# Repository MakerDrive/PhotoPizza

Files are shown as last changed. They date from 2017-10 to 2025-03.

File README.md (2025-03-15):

Watch the promo video (https://youtu.be/ocshAWL1mxE?si=FHEazX_rP1Yjf2Of)

# 📷 PhotoPizza DIY

**PhotoPizza** is an open-source project for creating a turntable that allows you to take pictures of objects from all directions (3D-photo-360 spin-photo). The control unit platform is based on Espruino.

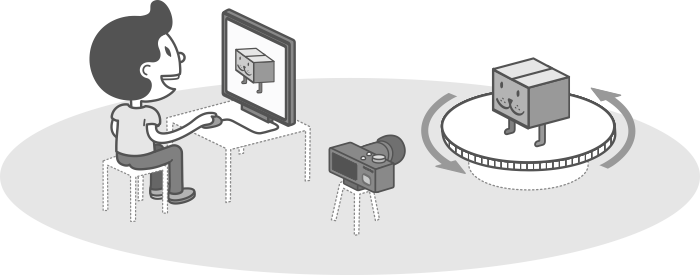
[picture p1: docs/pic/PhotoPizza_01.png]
PhotoPizza Turntable


## 📚 Documentation

Our documentation is organized into several sections for easier navigation:

1. [📢 About PhotoPizza](docs/01-about.md) - Project overview and message from the author
2. [🛠️ Hardware Requirements](docs/02-hardware.md) - List of components needed for the control unit
3. [🔄 Turntable Models](docs/03-turntable-models.md) - Different turntable sizes and their components
4. [📱 Control Methods](docs/04-control-methods.md) - IR Remote, Android App, and Wi-Fi control
5. [📸 Operation Guide](docs/05-operation-guide.md) - How to use PhotoPizza for shooting and calibration
6. [🌟 Join the Community](docs/06-community.md) - How to contribute and contact information
7. [🏺 3D Scanning Examples](docs/07-3d-scanning-examples.md) - Real-world examples of 3D scanning projects
8. [📰 Latest News](docs/08-news.md) - Recent updates and announcements

## ✨ Features

- 🔄 360° product photography
- 📱 Multiple control options (IR remote, Android app, Wi-Fi)
- 🛠️ DIY-friendly design
- 📊 Customizable shooting parameters
- 🎥 Support for both photo and video shooting
- 📐 Various turntable sizes (D250, D340, D480, D700, D850)
- 🔍 3D scanning with laser scanners
- 📷 3D scanning using photogrammetry methods

## 🚀 Quick Start

1. Choose your turntable size based on your needs
2. Gather all the required components
3. Follow the assembly instructions
4. Install the firmware
5. Connect to your camera
6. Start shooting amazing 360° photos!

## 📥 Downloads

- [📱 Android App](https://github.com/PhotoPizza/remote/blob/master/PhotoPizza.apk)
- [💾 Firmware](Firmware_for_D340_D480_D700/)
- [📐 Laser Cutting Drawings](Drawings_for_laser_cutting/)

## 📚 Related Articles
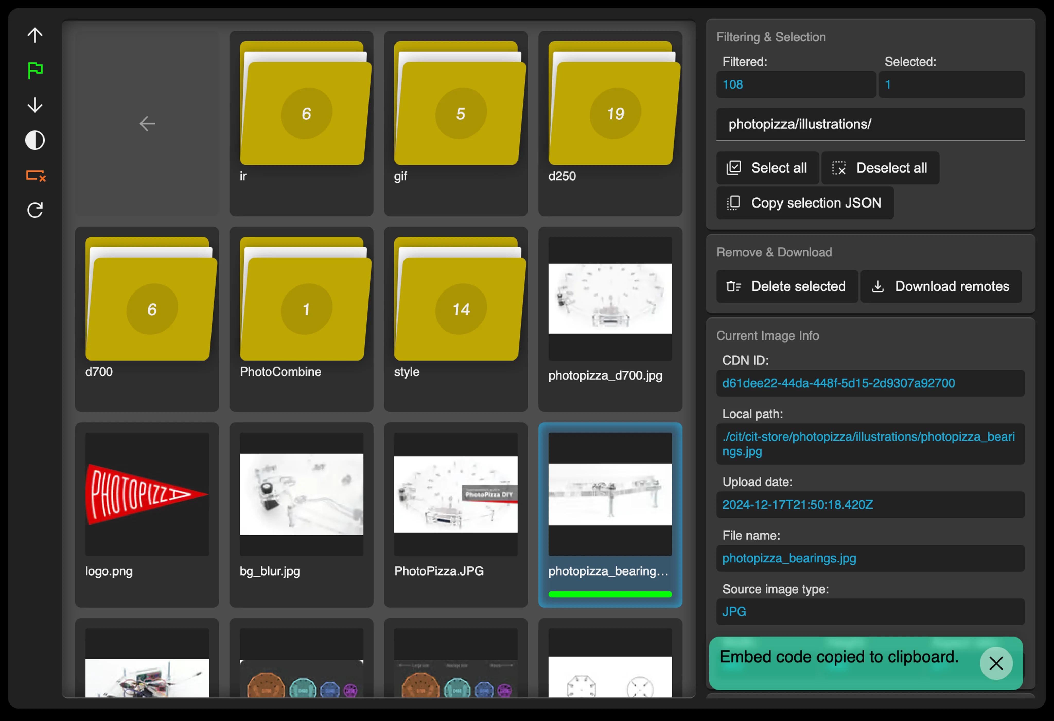
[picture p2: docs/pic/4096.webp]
PhotoPizza in action


- [📝 PhotoPizza: From the idea to the Open Source DIY Project](https://rnd-pro.com/pulse/PhotoPizza/)
- [📝 Interactive Media Spots](https://rnd-pro.com/pulse/interactive-media-spots/)
- [📝 ComplexScan AUTOBOX v1](https://rnd-pro.com/pulse/ComplexScan_AUTOBOX_v1/)
- [📝 ComplexScan](https://rnd-pro.com/pulse/ComplexScan/)
- [📝 Web Images: Problems and Solutions](https://rnd-pro.com/pulse/web-images-problem/)

## 📱 Social Media

Follow us on social media for updates, tips, and community showcases:

- [📸 Instagram](https://www.instagram.com/diy.photopizza/)
- [🎬 YouTube](https://www.youtube.com/@PhotoPizza)

## 📞 Contact

For inquiries, please contact: photopizza@rnd-pro.com

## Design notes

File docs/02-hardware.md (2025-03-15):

# 🛠️ Hardware Requirements

## External Control Unit

### 🔌 Electronics

- ESP32 Controller - 1
- Relay - 1
- Stepper motor driver board - 1
- Stepper motor driver - 1
- Heat sink - 1
- Power contact expansion board - 1
- IR receiver - 1
- Display - 1
- 3.5 Jack connector - 1
- Fan - 1
- Batteries for IR remote - 2

### 📦 Body Parts

- Base - 1
- Cover - 1
- Front panel - 1
- Screen mounting panel - 1
- Left panel with 3.5 Jack cutout - 1
- Right panel: fan - 1
- Rear panel - 1
- 3.5 Jack mounting part - 1
- IR receiver mounting part - 1
- IR remote - 1

### 🔩 Fasteners

- Screw 3*16 - 22
- Screw 3*25 - 2
- Nut M3 - 33
- Countersunk screw 6*35 - 4
- Nut M6 - 4
- Furniture nut M6 - 4

### 🧵 Wires

- Power wire 5V: male-female "+" 12 cm - 3
- Power wire 5V: male-female "-" 12 cm - 3
- Power wire 5V: female-female "+" 12 cm - 3
- Power wire 5V: female-female "-" 12 cm - 3
- Power wire 12V: male-male "+" long - 1
- Power wire 12V: male-male "-" long - 1
- Control wire: male-male 12 cm - 3
- Control wire: male-female 12 cm - 5
- Extension wire 3.5 Jack - 1
- Sync wire - 1

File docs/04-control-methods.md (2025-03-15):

# 📱 Control Methods

## 🎮 IR Remote Control

### Description of IR Remote Buttons

1. **Parameter control buttons:**
   - `1-9, 0`: Enter numerical values for various parameters.
   - `UP`: Move up through the menu.
   - `DOWN`: Move down through the menu.
   - `LEFT`: Move left through the menu.
   - `RIGHT`: Move right through the menu.
   - `OK`: Confirm selection or change a parameter, start and stop the shooting process.
   - `SETUP`: Enter and exit the parameter setup menu.

2. **Special buttons:**
   - `SAVE`: Save the current settings.
   - `SHOT`: Test shot.
   - `CALIBR`: System calibration.
   - `WIFI`: Enable Wi-Fi.

### How to Use the IR Remote Control

The remote allows you to fully control the turntable, set shooting parameters, and start/stop the shooting process.

## 📱 Android Application

### PhotoPizza Remote App

Now an official Android application is available that allows you to control the PhotoPizza turntable via Wi-Fi connection. The application provides a convenient interface for setting shooting parameters, starting and stopping the process, and saving configurations.

### ✨ Main Features:

- Connect to the PhotoPizza device via Wi-Fi
- Configure all shooting parameters (number of frames, delay, pause, speed, rotation angle)
- Start and stop the shooting process
- Calibrate the turntable
- Save and load user settings
- Test shot
- Infinite rotation mode for video shooting

### 📥 Where to Download:

- Project repository: [https://github.com/PhotoPizza/remote](https://github.com/PhotoPizza/remote)
- Download APK file: [https://github.com/PhotoPizza/remote/blob/master/PhotoPizza.apk](https://github.com/PhotoPizza/remote/blob/master/PhotoPizza.apk)

### 📋 Requirements:

- Android 5.0 or higher
- PhotoPizza device with firmware v7 (ESPRUINO) or newer
- Wi-Fi connection

### 🔌 First Connection Guide

The initial setup of the Android application involves the following steps:

1. **Create a Hotspot on Your Phone:**
   - Create a mobile hotspot with SSID `PhotoPizza` and password `9992030360`.
   - This will allow the control unit to connect to your phone directly.

2. **Power On the Control Unit:**
   - Turn on the PhotoPizza control unit.
   - During startup, the control unit will automatically connect to the hotspot you created.

3. **Connect Through the App:**
   - Open the PhotoPizza Remote app on your Android device.
   - The app will automatically detect and connect to the control unit.

4. **Optional: Configure for Home Network:**
   - You can continue using the hotspot method, or configure the system to use your home Wi-Fi network.
   - To use your home network, go to the app settings.
   - Enter your home Wi-Fi network parameters (SSID and password).
   - Save the settings.
   - Restart the control unit, and it will connect to your home network instead.
   - Your phone, when connected to the same home network, will be able to control the turntable without creating a hotspot.

## 🌐 Wi-Fi Control

### Connecting to Wi-Fi

The system can operate in two modes:

1. **Access Point (AP):**
   - The device creates an access point with SSID `PhotoPizza` and password `9992030360`.
   - To select this mode, set the `wirelessType` parameter to `ap`.

2. **Connecting to an Existing Network (Client):**
   - To connect to an existing network, set the `wirelessType` parameter to `conn`.
   - Set the network SSID in the `wifiSsid` parameter and the password in the `wifiPassword` parameter.

### Web Server

Wi-Fi control is an additional way to control the system. Through the web interface, you can manage the system state, change settings, and get current data.

1. The system launches a WebSocket server on the port specified in the configuration (`wsPort`).
2. Through the web interface, you can manage the system state, change settings, and get current data.

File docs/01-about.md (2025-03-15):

# 📢 About PhotoPizza

## A Message from the Author

**I had to leave my country. Currently, I don't have access to the equipment needed for developing and testing the project, but I plan to restore the project description and publish all the materials developed before my departure soon.**

**I am looking for like-minded individuals worldwide who want to earn money from the open-source project, sell ready-made equipment, and participate in its development. I will post your contact information on the website, provide additional information, and packaging blueprints. Clients who don't have time to assemble the equipment themselves will reach out to you. I will not take any percentage of your profit. You will be the official representatives of this project in your country.**

**For inquiries, please contact photopizza@rnd-pro.com.**

## 🔄 360° Product Photography Turntable

**PhotoPizza** is an open-source project for creating a turntable that allows you to take pictures of objects from all directions (3D-photo-360 spin-photo). The control unit platform is based on Espruino. You can self-assemble the device from available components using detailed instructions, and you do not need deep knowledge in electronics. The turntable is also suitable for 3D scanning using photogrammetry methods.

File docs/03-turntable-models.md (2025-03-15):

# 🔄 Turntable Models

## Turntable D340

### Acrylic Parts

- Base - 1
- Disk 340 cm - 1
- Motor mount - 1
- Motor spacer - 1
- Background disk, white 34 cm

### Fasteners

- Bearings 608ZZ for rollers - 8
- Bolt 8*40 for rollers and central axis - 9
- Nuts M8 for rollers, central axis, and legs - 26
- Clamps for rollers - 8
- Screw M8x60 DIN912 (legs) - 8
- Wing nuts M8 for leg mounting - 8
- Screw M6x35 for clamping system - 3
- Nut M6 for clamping system - 6
- Screw M3x16 for motor mounting - 4
- Spring for clamping system - 2
- Drive roller - 1
- Rubber for drive roller - 4

### Electrical Components

- Nema 17 stepper motor - 1
- Wire for motor connection - 1

## Turntable D480

### Acrylic Parts

- Base - 1
- Disk 480 cm - 1
- Motor mount - 1
- Motor spacer - 1
- Background disk, white 48 cm

### Fasteners

- Bearings 608ZZ for rollers - 12
- Bolt 8*40 for rollers and central axis - 13
- Nuts M8 for rollers, central axis, and legs - 38
- Clamps for rollers - 12
- Screw M8x60 DIN912 (legs) - 12
- Wing nuts M8 for leg mounting - 12
- Screw M6x35 for clamping system - 3
- Nut M6 for clamping system - 6
- Screw M3x16 for motor mounting - 4
- Spring for clamping system - 2
- Drive roller - 1
- Rubber for drive roller - 4

### Electrical Components

- Motor - 1
- Wire for motor connection - 1

## Turntable D700

### Acrylic Parts

- Base - 1
- Disk 70 cm - 1
- Motor mount - 1
- Motor spacer - 1
- Background disk, white 70 cm

### Fasteners

- Bearings 608ZZ for rollers - 24
- Bolt 8*40 for rollers and central axis - 25
- Nuts M8 for rollers, central axis, and legs - 62
- Clamps for rollers - 24
- Screw M8x60 DIN912 (legs) - 12
- Wing nuts M8 for leg mounting - 12
- Screw M6x35 for clamping system - 3
- Nut M6 for clamping system - 6
- Screw M3x16 for motor mounting - 4
- Spring for clamping system - 2
- Drive roller - 1
- Rubber for drive roller - 4

### Electrical Components

- Motor - 1
- Wire for motor connection - 1

## Turntable D850

### Acrylic Parts

- Base - 1
- Disk 85 cm - 1
- Motor mount - 1
- Motor spacer - 1
- Background disk, white 85 cm

### Fasteners

- Bearings 608ZZ for rollers - 24
- Bolt 8*40 for rollers and central axis - 25
- Nuts M8 for rollers, central axis, and legs - 62
- Clamps for rollers - 24
- Screw M8x60 DIN912 (legs) - 12
- Wing nuts M8 for leg mounting - 12
- Screw M6x35 for clamping system - 6
- Nut M6 for clamping system - 12
- Screw M3x16 for motor mounting - 8
- Spring for clamping system - 4
- Drive roller - 2
- Rubber for drive roller - 8

### Electrical Components

- Motor - 2
- Wire for motor connection - 2

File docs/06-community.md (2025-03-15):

# 🌟 Join the Community

**PhotoPizza** is a great opportunity to create 3D photos and spin photos yourself. Join our community and help make the project even better!

## 📞 Contact Information

- 📧 Email: photopizza@rnd-pro.com
- 🌐 GitHub: [https://github.com/MakerDrive/PhotoPizza](https://github.com/MakerDrive/PhotoPizza)
- 📱 Android App: [https://github.com/PhotoPizza/remote](https://github.com/PhotoPizza/remote)

## 🤝 How to Contribute

We welcome contributions from the community! Here are some ways you can help:

1. **Development**: Improve the firmware, add new features, fix bugs
2. **Documentation**: Help improve or translate the documentation
3. **Testing**: Test the device and report issues
4. **Spread the word**: Share your experience with the project on social media
5. **Become a representative**: Sell ready-made equipment in your country

## 📸 Share Your Projects

We'd love to see what you create with PhotoPizza! Share your projects, photos, and videos with the community.

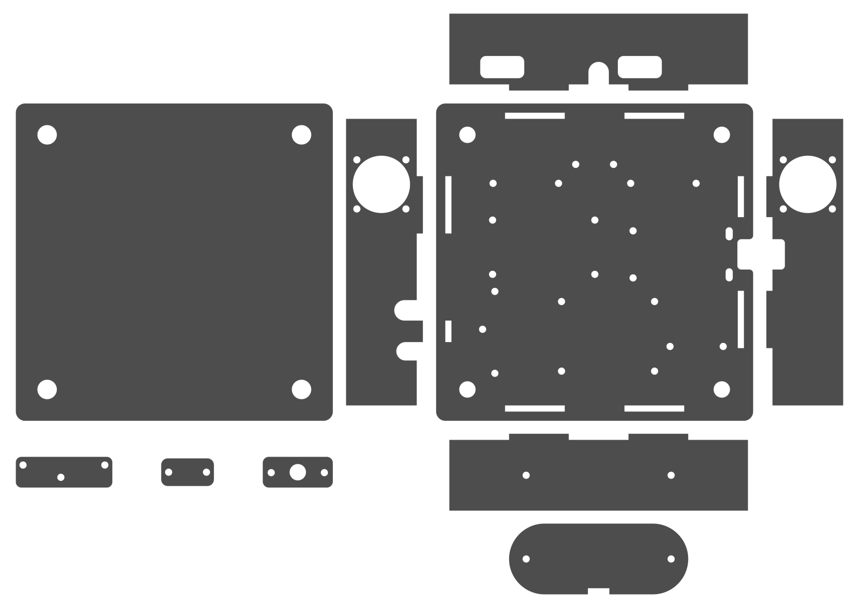
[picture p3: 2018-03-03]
Drawings_for_laser_cutting/Drawings_PhotoPizza_v3-5/PhotoPizza_Control_Unit_v5_Thickness_3mm/ESP32/Control Unit v5.jpg

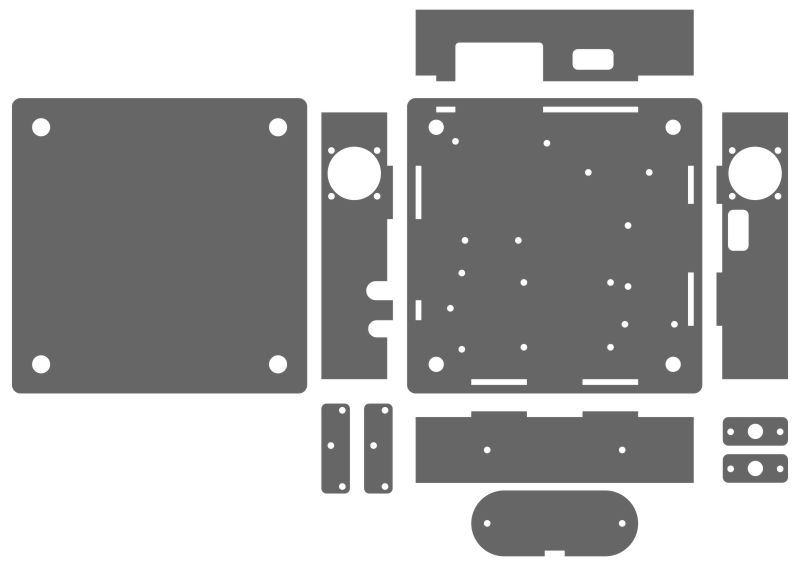
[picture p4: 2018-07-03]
Drawings_for_laser_cutting/Drawings_PhotoPizza_v3-5/PhotoPizza_Control_Unit_v5_Thickness_3mm/ESP32UNO/Control Unit v5.jpg

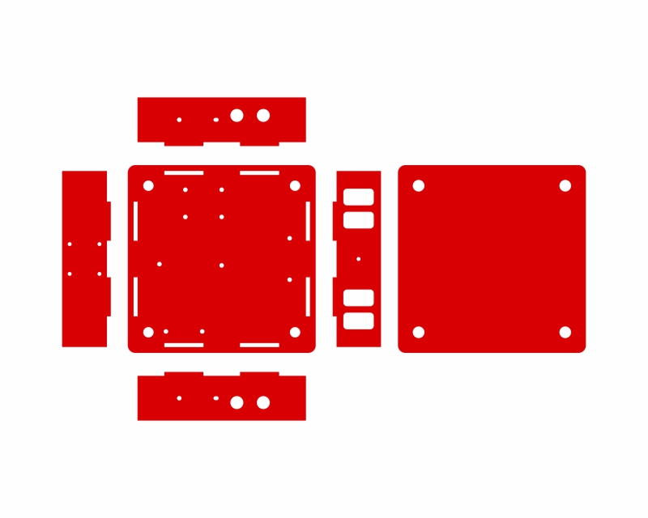
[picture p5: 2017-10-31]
Drawings_for_laser_cutting/Drawings_PhotoPizza_v3-5/PhotoPizza_Control_Unit_v3-4_Thickness_3mm/PhotoPizza Control block v3.jpg

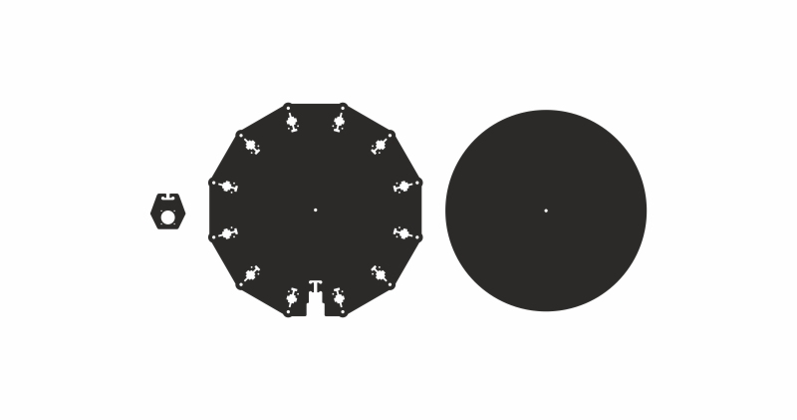
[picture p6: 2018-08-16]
Drawings_for_laser_cutting/Drawings_PhotoPizza_v3-5/PhotoPizza_D480_v3-5_Thickness_10mm/PhotoPizza D480 v3.jpg

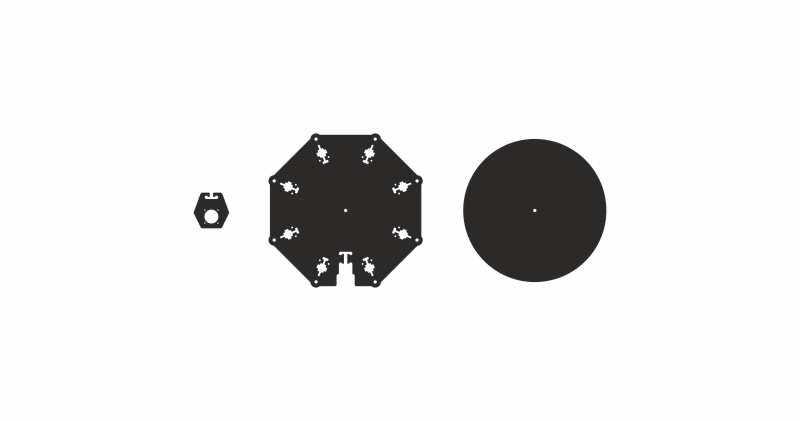
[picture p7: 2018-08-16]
Drawings_for_laser_cutting/Drawings_PhotoPizza_v3-5/PhotoPizza_D340_v3-5_Thickness_10mm/PhotoPizza D340 v3.jpg

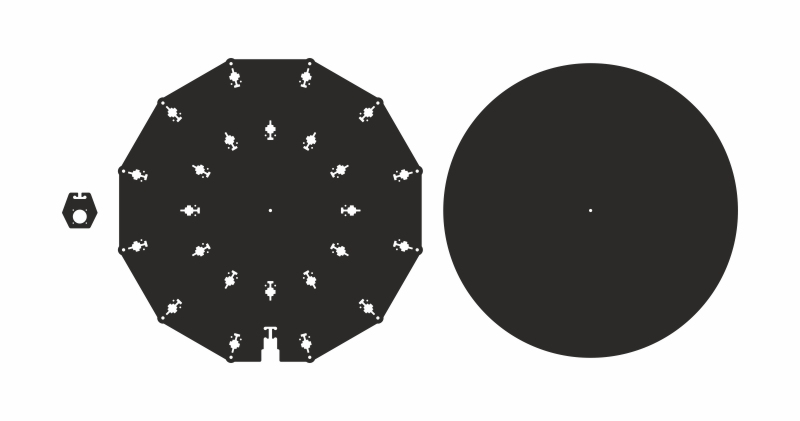
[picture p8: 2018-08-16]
Drawings_for_laser_cutting/Drawings_PhotoPizza_v3-5/PhotoPizza_D700_v3-5_Thickness_10mm/PhotoPizza D700 v3.jpg

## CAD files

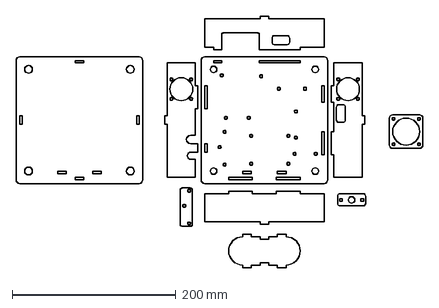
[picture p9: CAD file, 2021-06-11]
Drawings_for_laser_cutting/Drawings_PhotoPizza_v7/PhotoPizza_Control_Unit_v7_Thickness_3mm/PhotoPizza_Control_Unit_v7_Thickness_3mm.dxf
497.7 x 307.1 mm

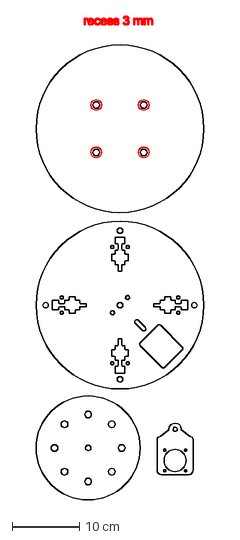
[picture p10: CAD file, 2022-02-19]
Drawings_for_laser_cutting/Drawings_PhotoPizza_v7/PhotoPizza_D250_v7_Thickness_10mm/D250.dxf
25.0 x 72.1 cm

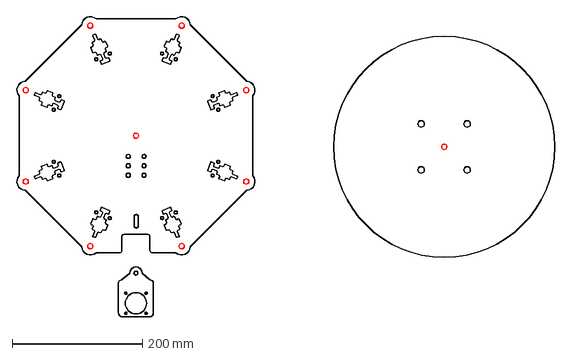
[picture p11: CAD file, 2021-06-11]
Drawings_for_laser_cutting/Drawings_PhotoPizza_v7/PhotoPizza_D340_v7_Thickness_10mm/PhotoPizza_D340_v7_Thickness_10mm.dxf
828.2 x 462.6 mm

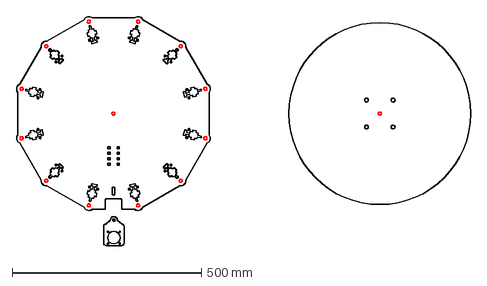
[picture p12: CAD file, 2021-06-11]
Drawings_for_laser_cutting/Drawings_PhotoPizza_v7/PhotoPizza_D480_v7_Thickness_10mm/PhotoPizza_D480_v7_Thickness_10mm.dxf
1199.8 x 605.3 mm

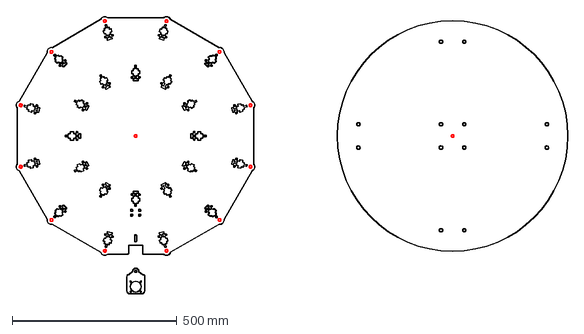
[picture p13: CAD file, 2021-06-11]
Drawings_for_laser_cutting/Drawings_PhotoPizza_v7/PhotoPizza_D700_v7_Thickness_10mm/PhotoPizza_D700_v7_Thickness_10mm.dxf
1675.6 x 841.3 mm

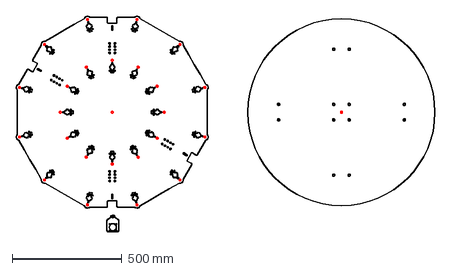
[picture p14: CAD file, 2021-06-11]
Drawings_for_laser_cutting/Drawings_PhotoPizza_v7/PhotoPizza_D850_v7_Thickness_10mm/PhotoPizza_D850_v7_Thickness_10mm.dxf
1904.6 x 981.7 mm

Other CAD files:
Drawings_for_laser_cutting/Drawings_PhotoPizza_v3-5/PhotoPizza_Control_Unit_v5_Thickness_3mm/ESP32/Control Unit v5.dwg
Drawings_for_laser_cutting/Drawings_PhotoPizza_v3-5/PhotoPizza_Control_Unit_v5_Thickness_3mm/ESP32UNO/Control Unit v5.dwg
Drawings_for_laser_cutting/Drawings_PhotoPizza_v3-5/PhotoPizza_D340_v3-5_Thickness_10mm/PhotoPizza D340 v3.dwg
Drawings_for_laser_cutting/Drawings_PhotoPizza_v3-5/PhotoPizza_D480_v3-5_Thickness_10mm/PhotoPizza D480 v3.dwg
Drawings_for_laser_cutting/Drawings_PhotoPizza_v3-5/PhotoPizza_D700_v3-5_Thickness_10mm/PhotoPizza D700 v3.dwg
Drawings_for_laser_cutting/Drawings_PhotoPizza_v7/PhotoPizza_Control_Unit_v7_Thickness_3mm/PhotoPizza_Control_Unit_v7_Thickness_3mm.dwg
Drawings_for_laser_cutting/Drawings_PhotoPizza_v7/PhotoPizza_D250_v7_Thickness_10mm/D250.dwg
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

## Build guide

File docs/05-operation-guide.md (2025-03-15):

# 📸 Operation Guide

## 📷 Shooting Process

1. **Object Placement:**
   - Place the item you want to photograph on the turntable.

2. **Setting Parameters:**
   - Use the IR remote or Android app to set the necessary shooting parameters:
     - Number of frames (`frame`).
     - Delay (`delay`) - delay time in milliseconds (e.g., `1000` milliseconds = 1 second).
     - Pause (`pause`) - pause time in milliseconds (e.g., `500` milliseconds = 0.5 seconds).
     - Speed (`speed`) - rotation speed in steps per second.
     - Rotation angle (`degreesX`) - rotation angle in degrees.

3. **Start Shooting:**
   - Press the `OK` button on the IR remote or the corresponding button in the app to confirm the settings.
   - To start the shooting process, press the `OK` button again. The turntable will start rotating and taking pictures automatically according to the set parameters.

4. **Stop Shooting:**
   - To stop the shooting process, press the `OK` button again.

5. **Infinite Shooting:**
   - To enable the infinite shooting mode, use the `"infinity"` command.

6. **Video Shooting:**
   - For video shooting, set the parameters for continuous rotation and turn on the camera in video mode. The turntable will rotate smoothly, providing even shooting from all sides.

7. **Saving Settings:**
   - After shooting, if you want to save the current settings for future shoots, press the `SAVE` button on the IR remote or use the save function in the app.

## 🔄 Calibration Process

### Why Calibration is Needed

Turntable calibration is necessary for accurately determining the rotation angle and ensuring correct object positioning. This allows the table to rotate precisely 360 degrees, returning to the starting point, which is important for creating high-quality 3D models, panoramic photos, and video shooting.

### Calibration Steps

1. **Preparation:**
   - Place the item opposite the drive roller on the turntable.

2. **Start Calibration:**
   - Press the `CALIBR` button on the IR remote or use the calibration function in the app to start the calibration process.

3. **Calibration Process:**
   - The turntable will start rotating. Stop it when the disk has rotated 360 degrees and is opposite the drive roller.
   - To stop the rotation, press the `OK` button.

4. **Saving Calibration:**
   - After completing the calibration process, press the `SAVE` button on the IR remote or use the save function in the app to save the settings.

## ⚙️ System Management

### Saving Configuration

To save the current settings, use the "Save Config" command in the management interface or press the `SAVE` button on the IR remote.

### Connecting to Wi-Fi

1. When connecting to Wi-Fi, the status is displayed on the screen.
2. If the connection is lost, the system will automatically attempt to reconnect.

## 📊 Working with Screens

### Status Display

The screen displays current settings and system status, such as the number of remaining frames, speed, and IP address.

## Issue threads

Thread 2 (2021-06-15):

photopizza_esp32_v7_2_old_pin.min.js

tornadocoin, 2021-06-15:
the code is unreadable. The device does not work after uploading

ajayjob2011, 2021-08-24:
> the code is unreadable. The device does not work after uploading

The code is working, But my stepper gets hot.

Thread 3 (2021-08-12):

Code incompatible with the last Espruino Firmware

BullzLabz, 2021-08-12:
Hello, thank you for this amazing project!

Could you please update the code for it work with the **latest Espruino Firmware 2v09** ?

Or give the guidelines and directives so that I can help you and contribute to your project by updating the code.

I tried to upload your code on all versions of Espruino Firmware, but only the **1v95** version works.

ajayjob2011, 2021-08-24:
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

Hi friend, Direct upload this v7 Espruino ESP32 it's working fine.

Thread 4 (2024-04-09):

project still alive?

MattFog, 2024-04-09:
I'd like to build a Photopizza, but I can't seem to find overall instructions, BOM, guide, etc.  The website appears to be down as well - does anyone know the status?

TheSchirki, 2024-06-10:
Same question here. @3d-photo-360 is it possible that you have a look on your website?

trueslator, 2024-07-01:
Couple of years ago, I bought a turntable for the company where I'm working for. This was way before the world got crazy in 2022. This turntable is still alive and working fine. In the past, I build a second controller and constructed a housing out of the drawings for 3D printing, I'm visiting our warehouse tomorrow to do some trainings/workshop for product photos. I will take detailed photos of the original turntable because I will build another one for my selfe. I will get some idea how to assamble it. The laser cutter drawings will help me to build one out of playwood. With a 400mm by 400mm - 20watt laser cutter/engraver I assume that I can build a 380mm version. I have also some more stuff to share, maybe it could be helpfull for someone. Let me know I should share my informations and stuff with you?

TheSchirki, 2024-07-02:
@trueslator  for me it would be interesting to get a manual to assemble the physical parts of the table, but that's not my main issue. It would be great to have a list of electrical parts needed, a wiring plan and how to set up the system.

trueslator, 2024-07-02:
@TheSchirki this would be possible. I build one controller by myself and use it for 360° panorama photos like this: http://www.meine-bilderbox.de/pano/thiele/thiele01.html and for a slider - the controller is very flexible. Give me a couple of days to find the original order which I did via Ali Express. Also the wiring wasn't that complicated.

trueslator, 2024-07-13:
I have reconstructed the controller unit with fritzing and have also the BOM available. I already found that somebody forked this project. I can share my data that this can be uploaded to the forked project, Any idea how to contact the owner of the forked project?

TheSchirki, 2024-07-18:
Where did you find a forked project? could you link it? And I'd appreciate it if you would upload your data there.

trueslator, 2024-07-18:
The creator of this issue forked it back in April. [PhotoPizza-2024](https://github.com/dangerweenie/PhotoPizza-2024). I can't add something to this forked project because the upload is blocked.

TheSchirki, 2024-07-24:
@trueslator I saw that you forked @dangerweenie s project. Would you upload your schematics and a brief instruction?

TheSchirki, 2024-07-24:
Because I'm quite new to coding and I don't really get what the "Firmware V7_6" or why there's nothing about the motor controlling. Same with all the Header files in the Arduino folder. The way I used and coded an Arduino were quite different. So I'm basically standing in front of all the code snippets and have no idea where to start or what to do with them. Any help is deeply appreciated.

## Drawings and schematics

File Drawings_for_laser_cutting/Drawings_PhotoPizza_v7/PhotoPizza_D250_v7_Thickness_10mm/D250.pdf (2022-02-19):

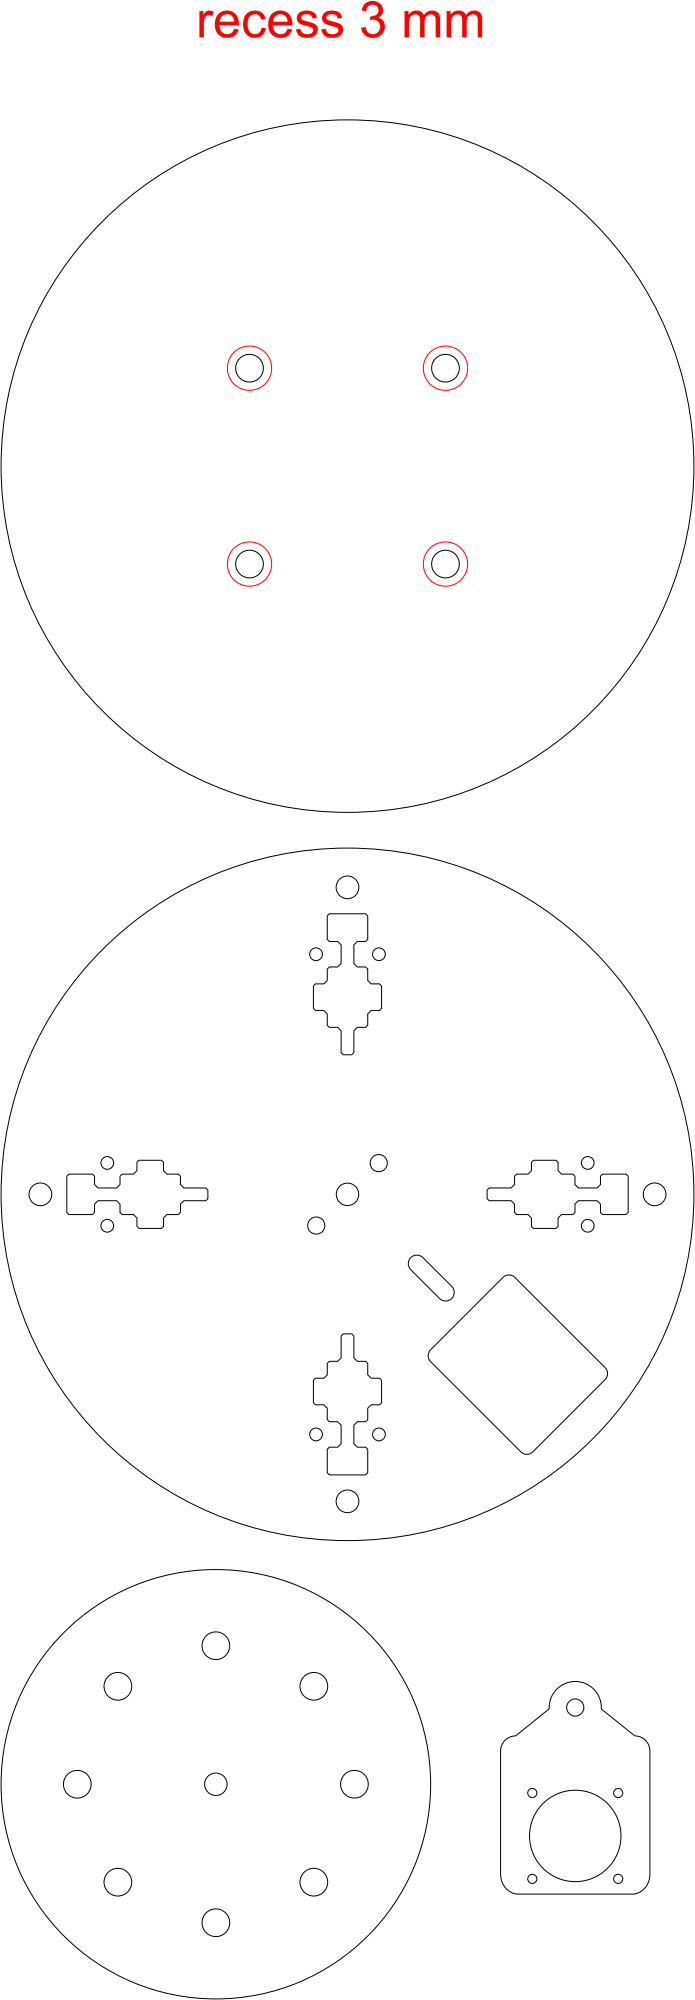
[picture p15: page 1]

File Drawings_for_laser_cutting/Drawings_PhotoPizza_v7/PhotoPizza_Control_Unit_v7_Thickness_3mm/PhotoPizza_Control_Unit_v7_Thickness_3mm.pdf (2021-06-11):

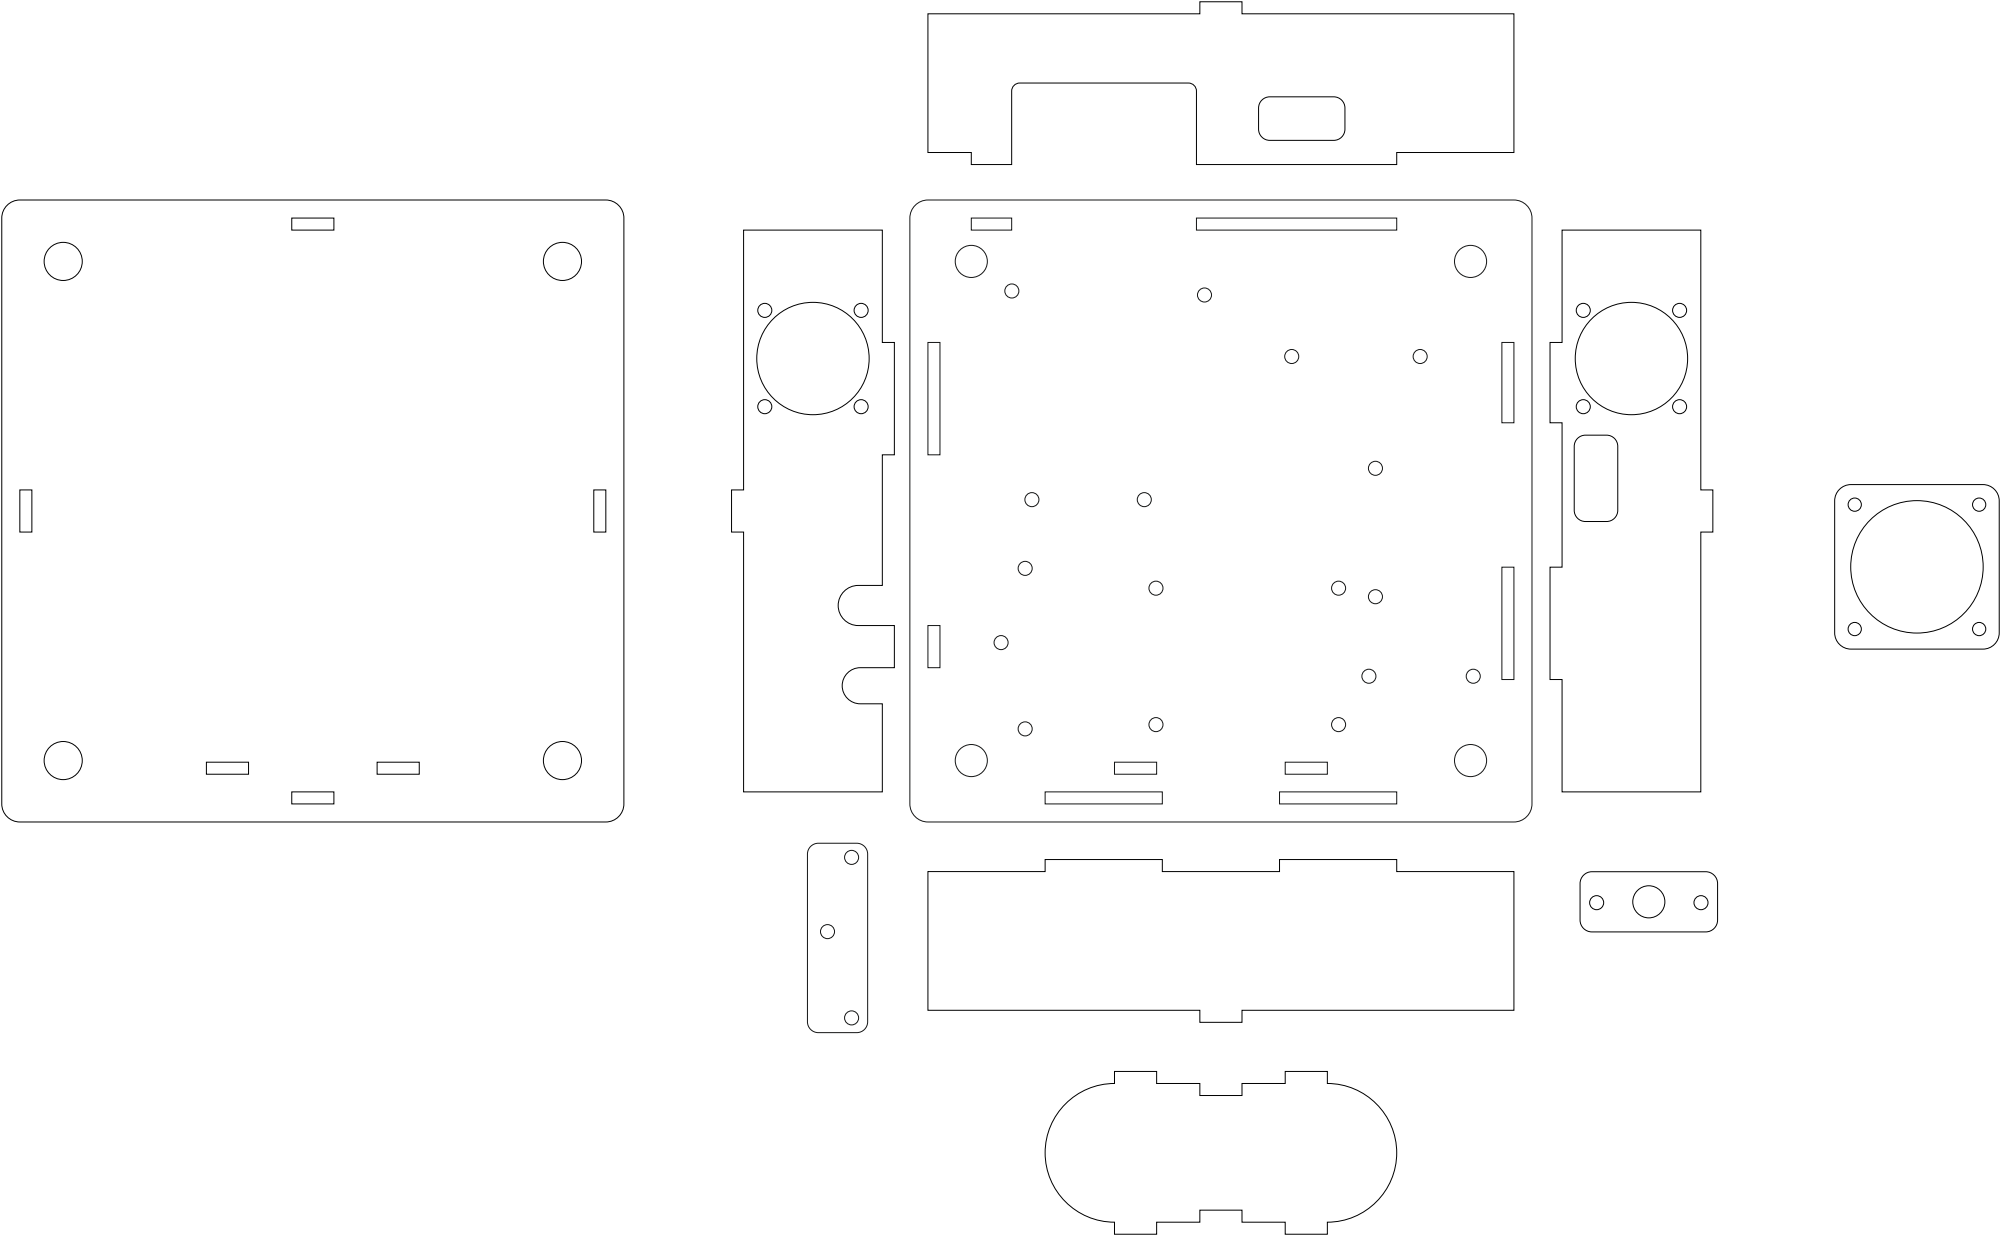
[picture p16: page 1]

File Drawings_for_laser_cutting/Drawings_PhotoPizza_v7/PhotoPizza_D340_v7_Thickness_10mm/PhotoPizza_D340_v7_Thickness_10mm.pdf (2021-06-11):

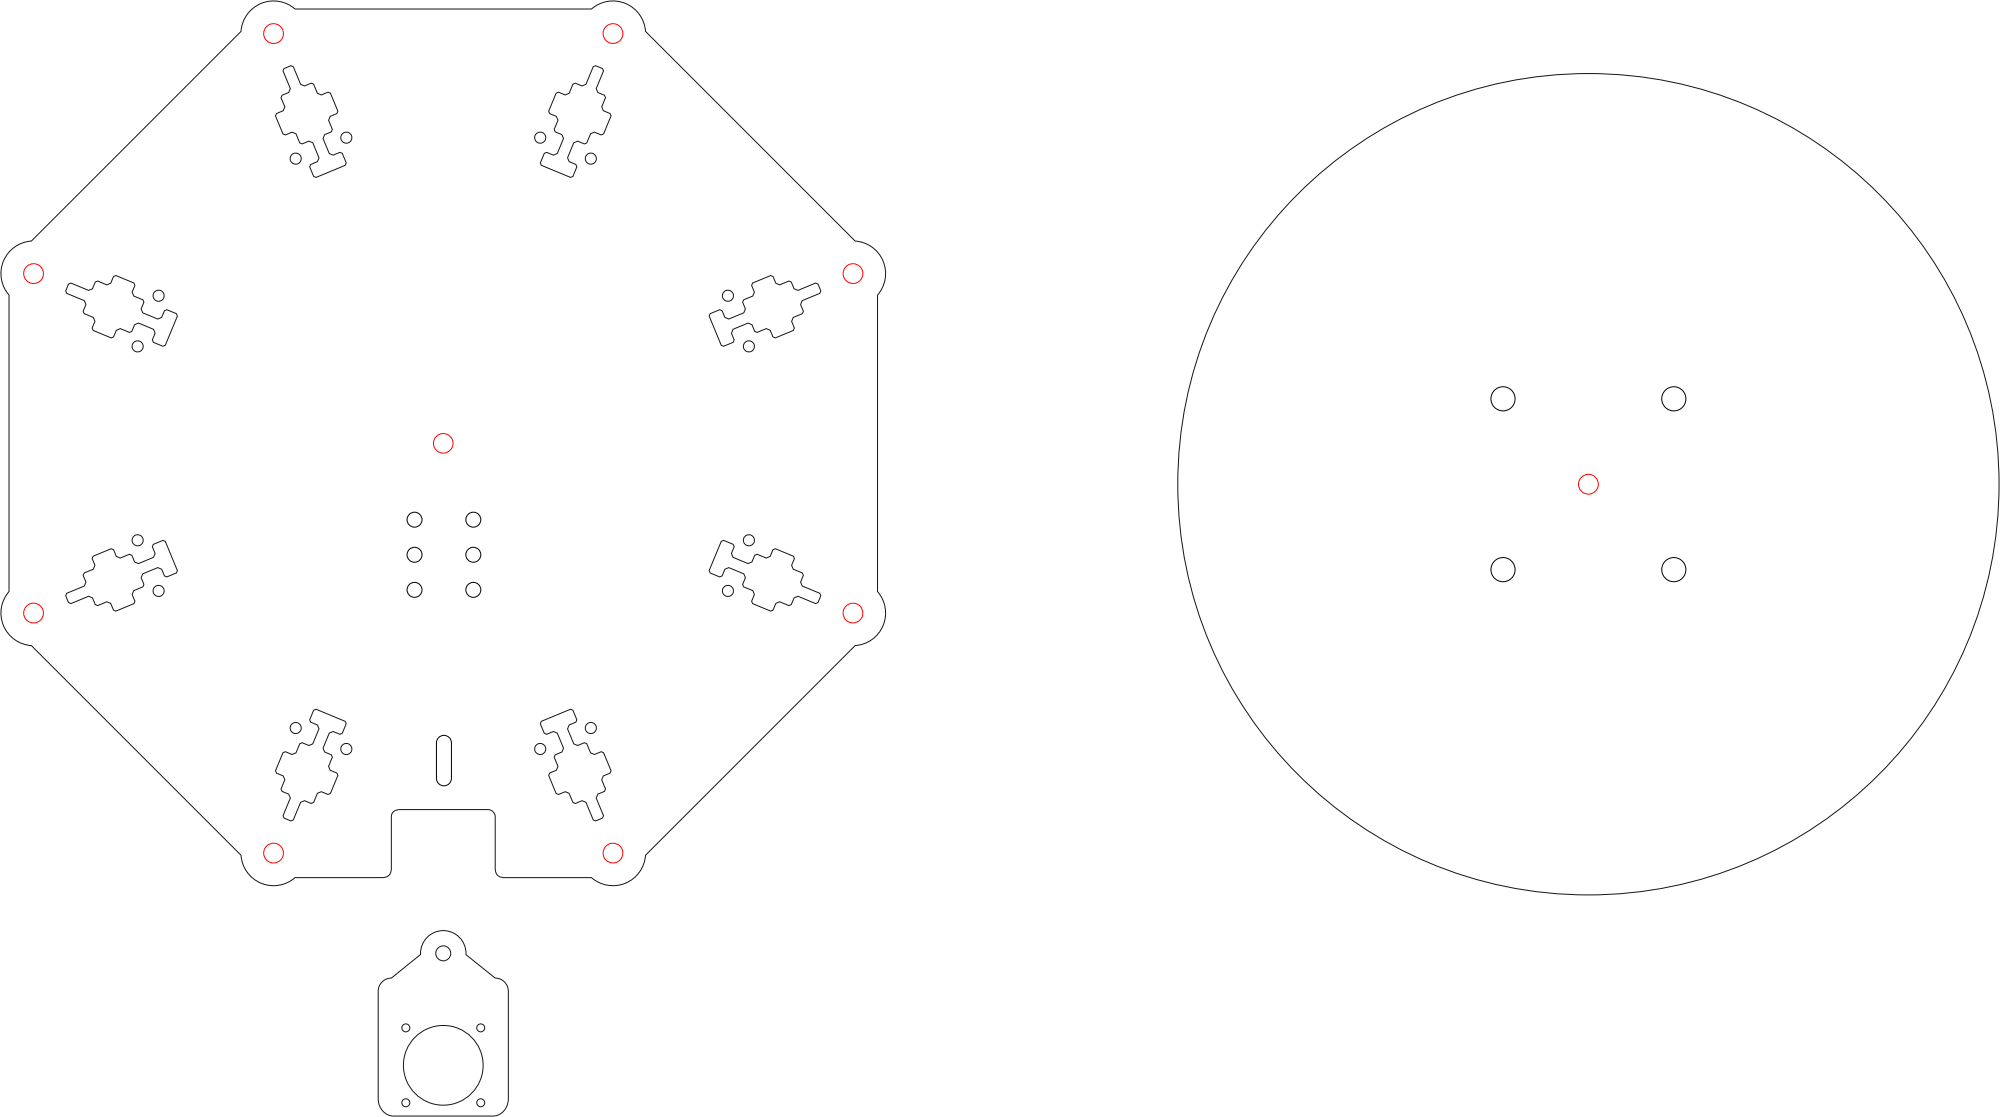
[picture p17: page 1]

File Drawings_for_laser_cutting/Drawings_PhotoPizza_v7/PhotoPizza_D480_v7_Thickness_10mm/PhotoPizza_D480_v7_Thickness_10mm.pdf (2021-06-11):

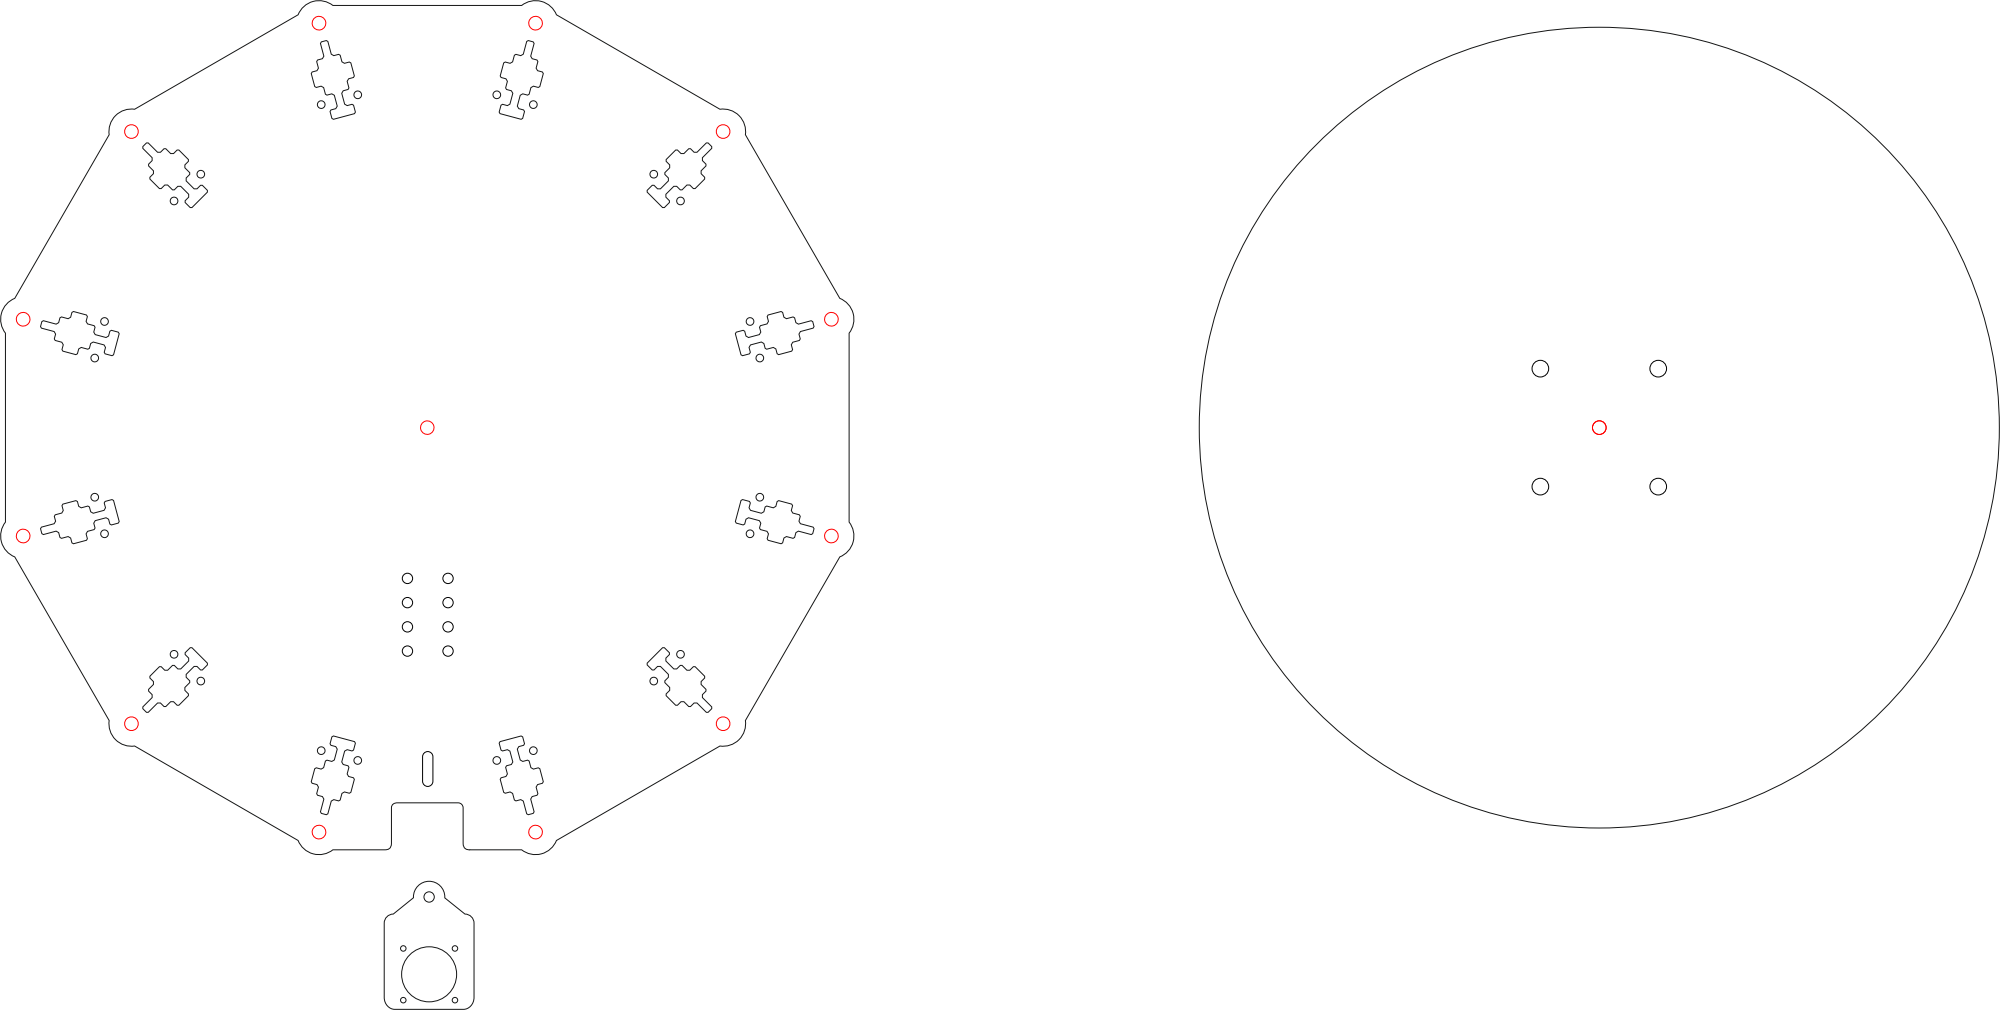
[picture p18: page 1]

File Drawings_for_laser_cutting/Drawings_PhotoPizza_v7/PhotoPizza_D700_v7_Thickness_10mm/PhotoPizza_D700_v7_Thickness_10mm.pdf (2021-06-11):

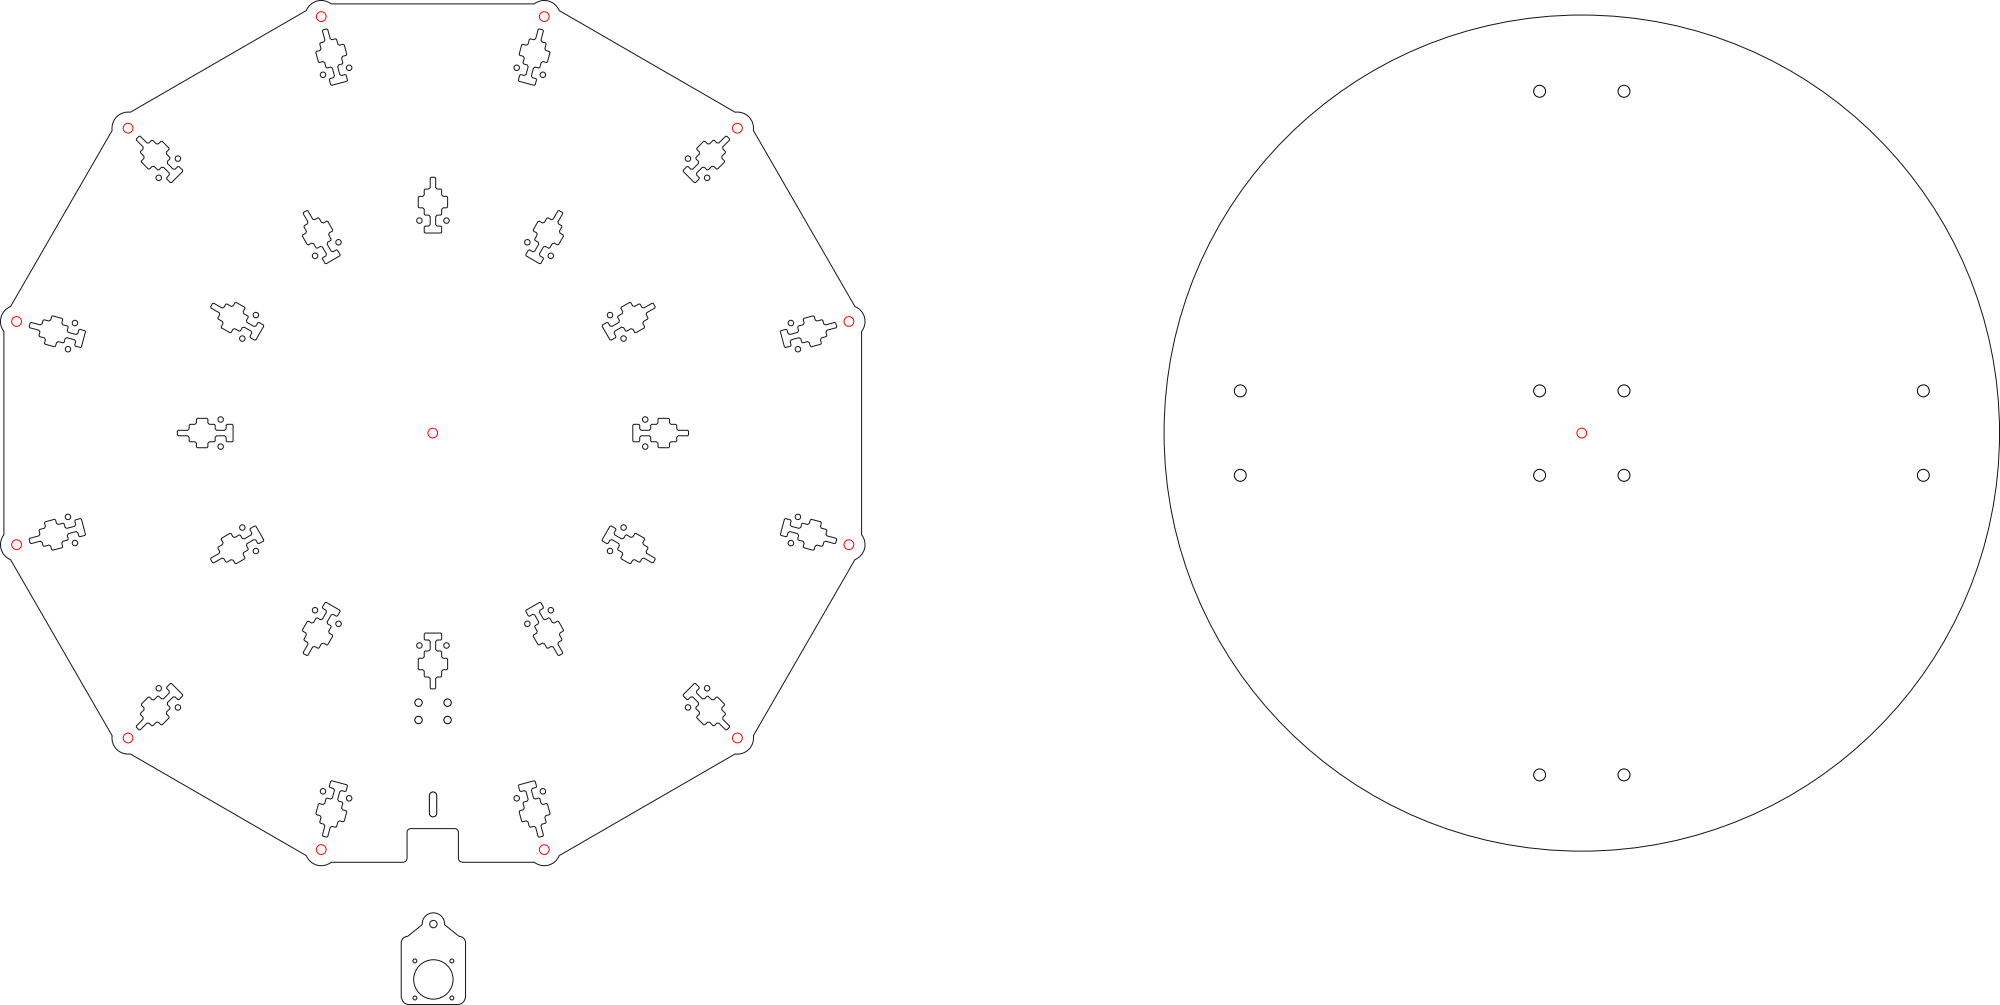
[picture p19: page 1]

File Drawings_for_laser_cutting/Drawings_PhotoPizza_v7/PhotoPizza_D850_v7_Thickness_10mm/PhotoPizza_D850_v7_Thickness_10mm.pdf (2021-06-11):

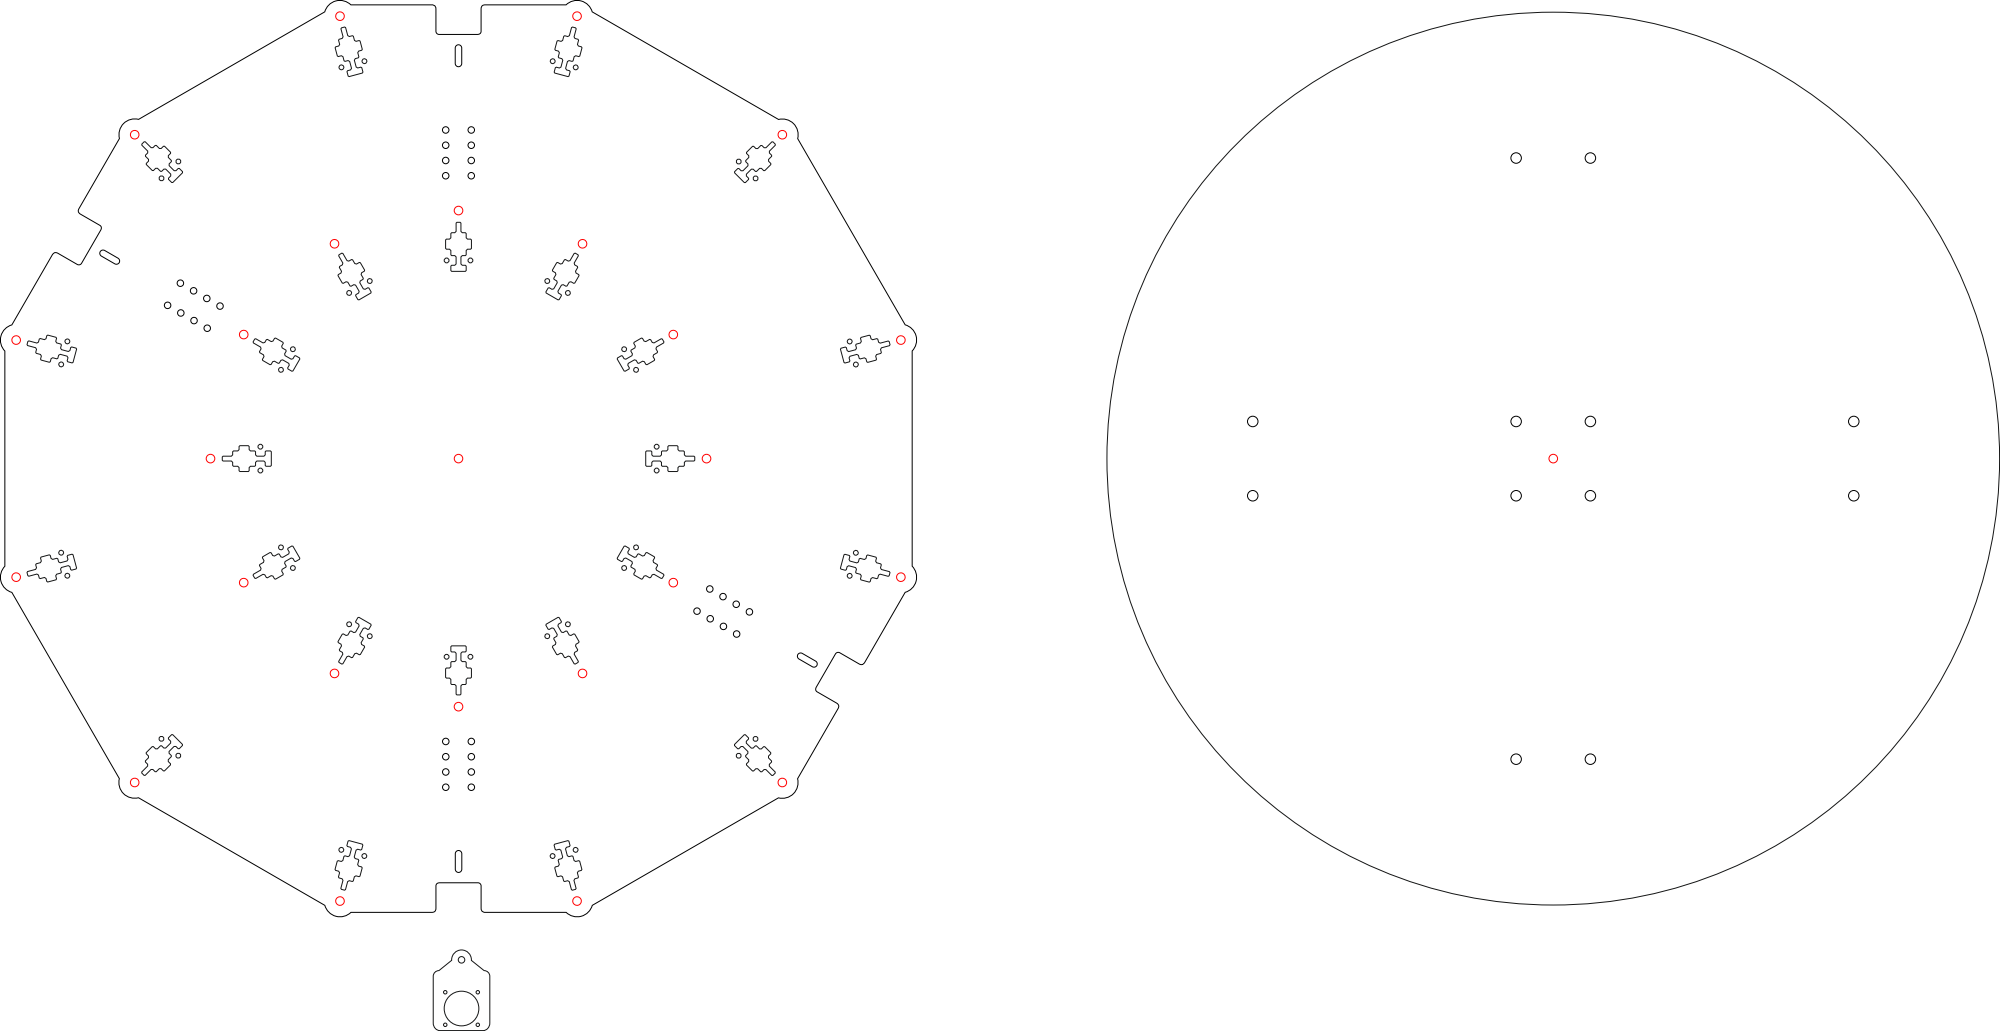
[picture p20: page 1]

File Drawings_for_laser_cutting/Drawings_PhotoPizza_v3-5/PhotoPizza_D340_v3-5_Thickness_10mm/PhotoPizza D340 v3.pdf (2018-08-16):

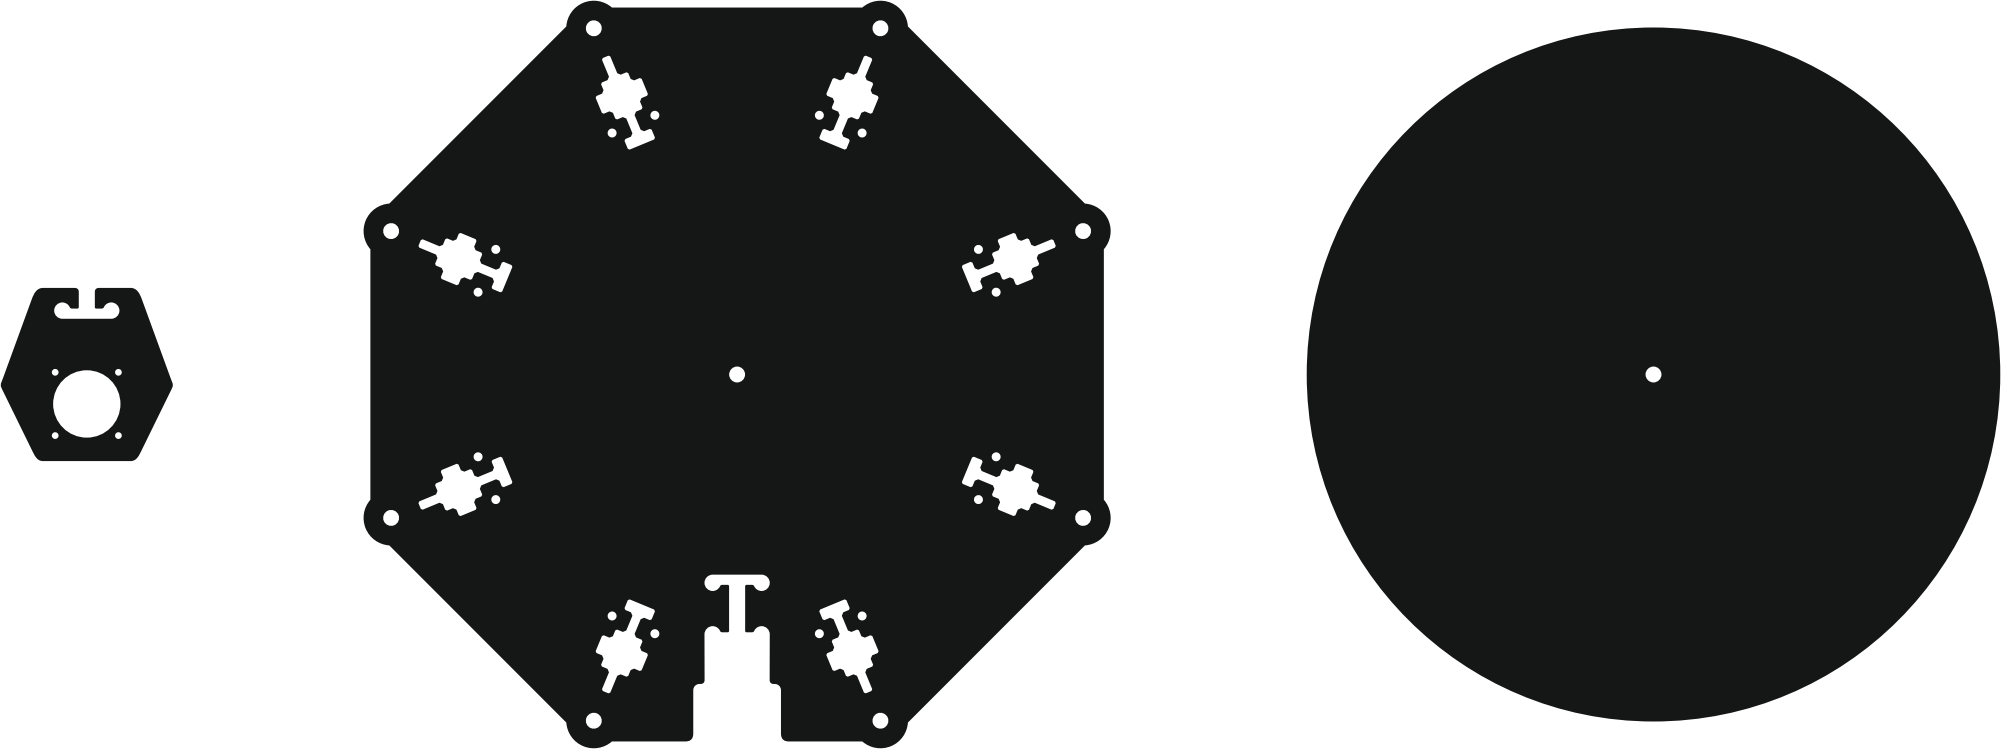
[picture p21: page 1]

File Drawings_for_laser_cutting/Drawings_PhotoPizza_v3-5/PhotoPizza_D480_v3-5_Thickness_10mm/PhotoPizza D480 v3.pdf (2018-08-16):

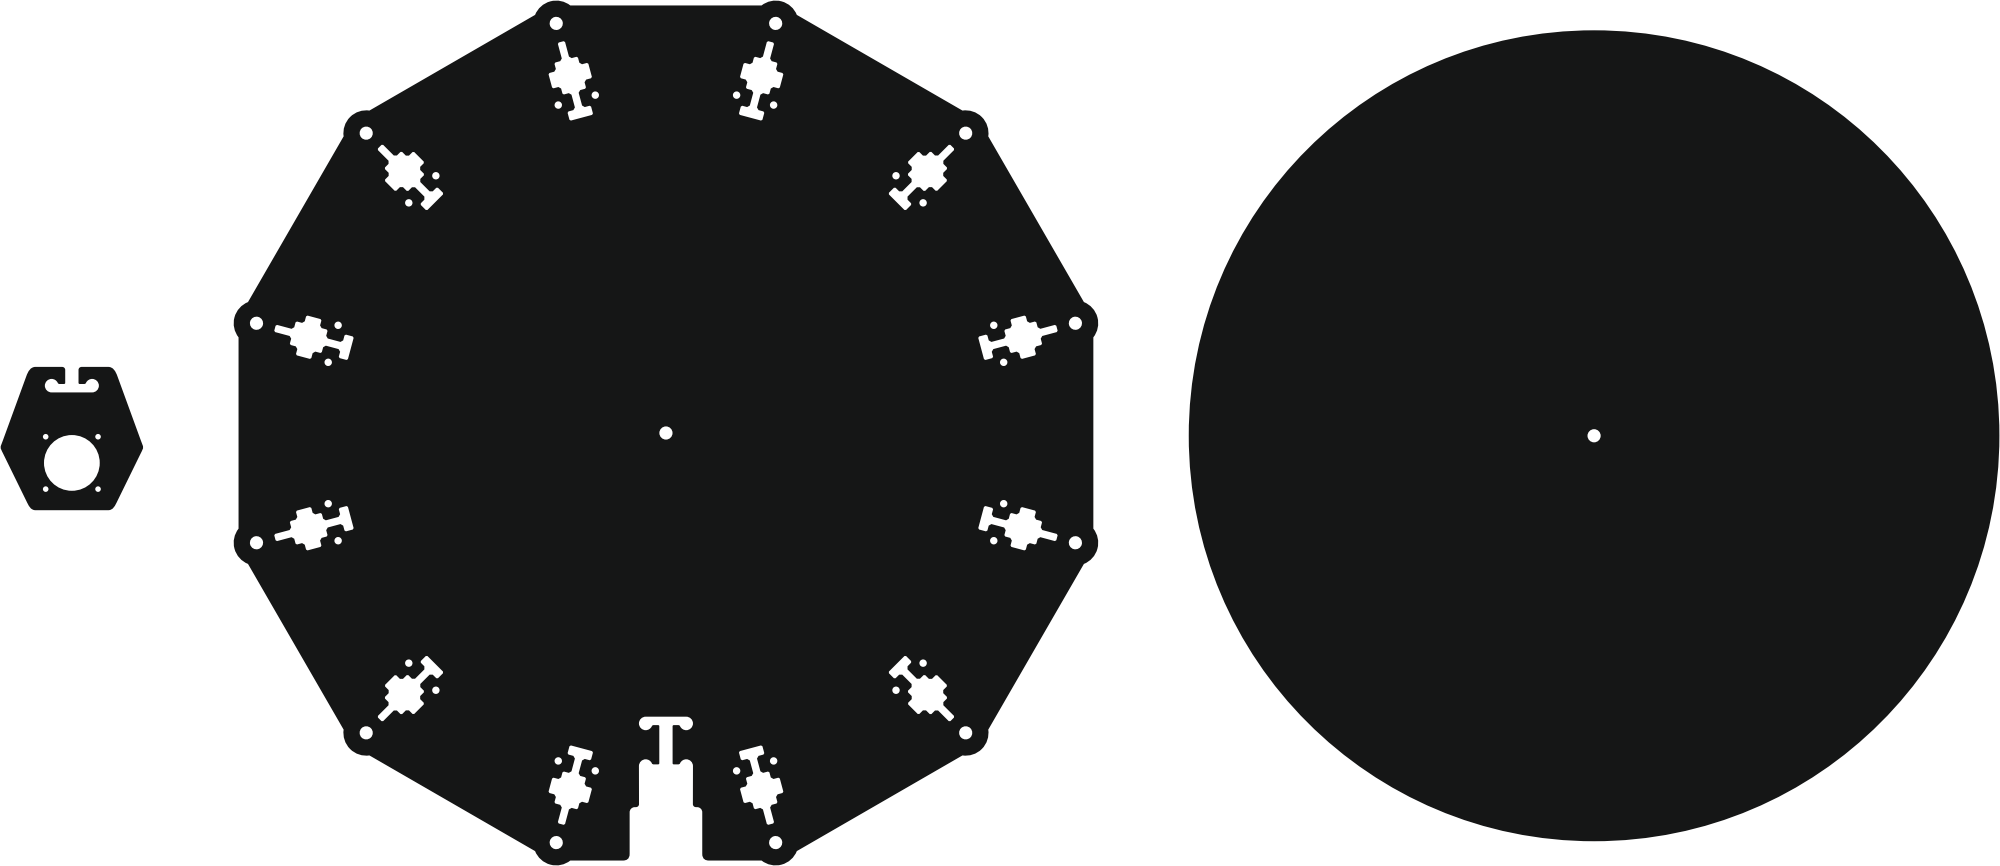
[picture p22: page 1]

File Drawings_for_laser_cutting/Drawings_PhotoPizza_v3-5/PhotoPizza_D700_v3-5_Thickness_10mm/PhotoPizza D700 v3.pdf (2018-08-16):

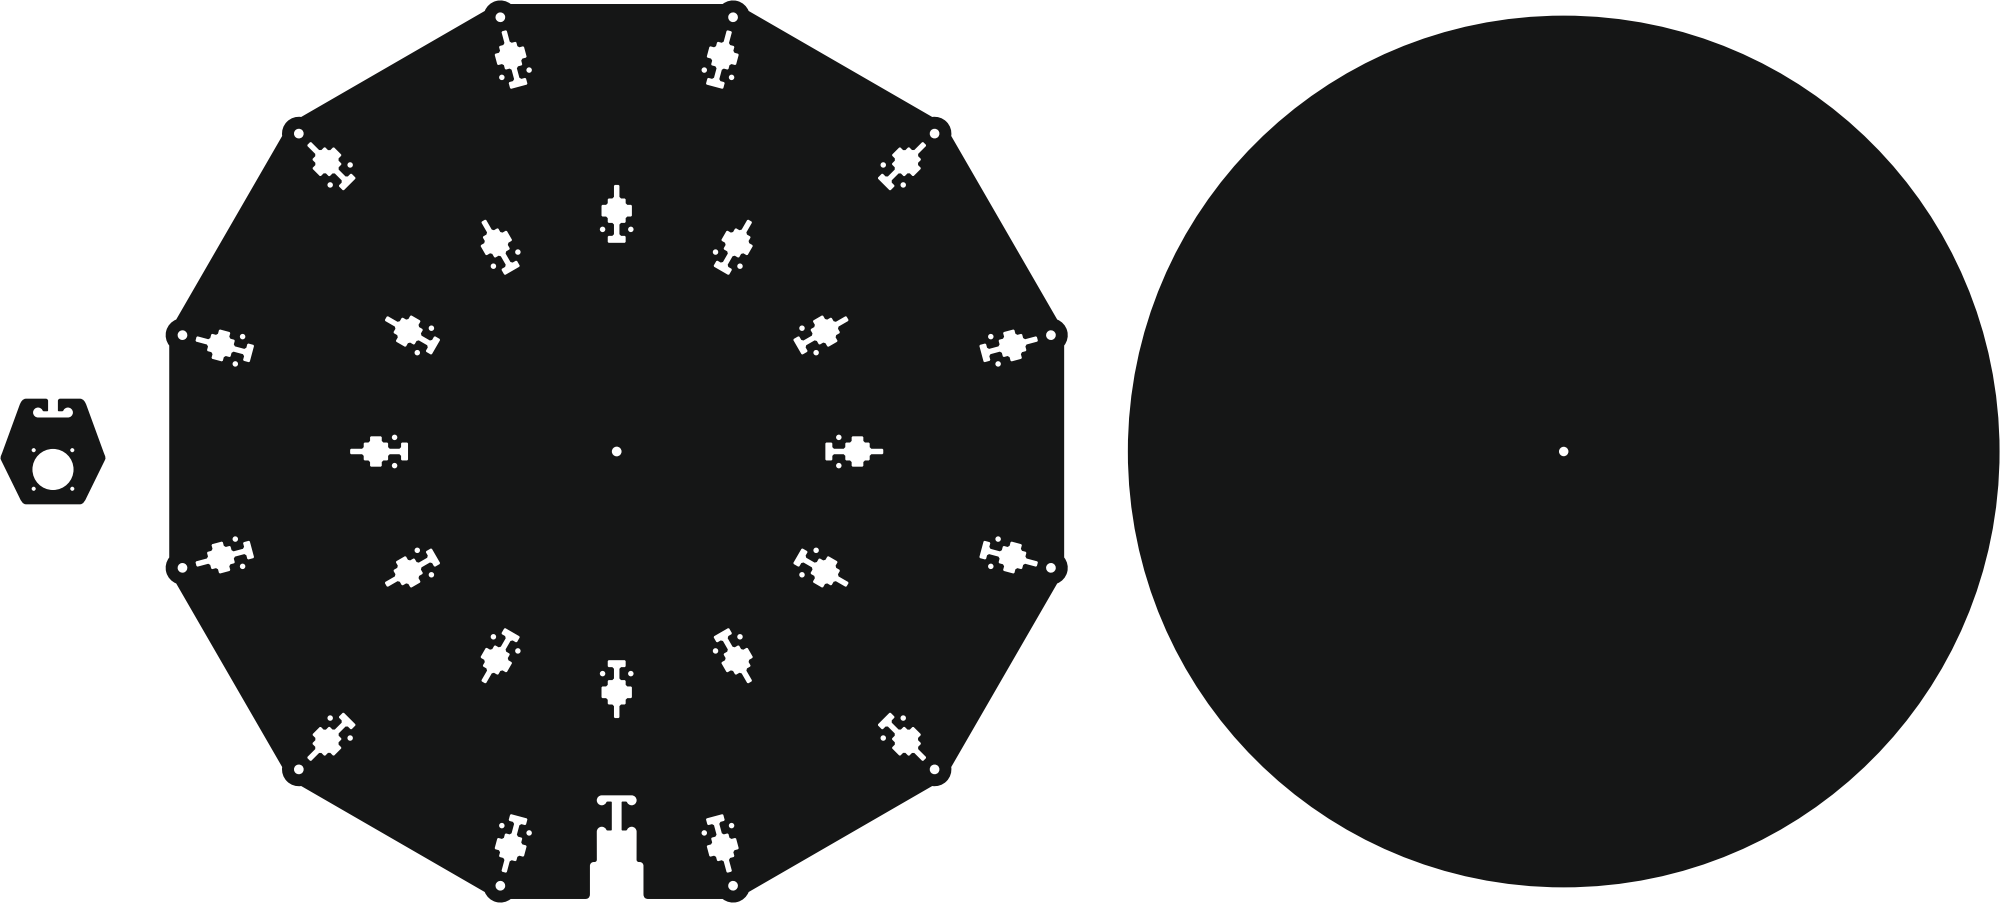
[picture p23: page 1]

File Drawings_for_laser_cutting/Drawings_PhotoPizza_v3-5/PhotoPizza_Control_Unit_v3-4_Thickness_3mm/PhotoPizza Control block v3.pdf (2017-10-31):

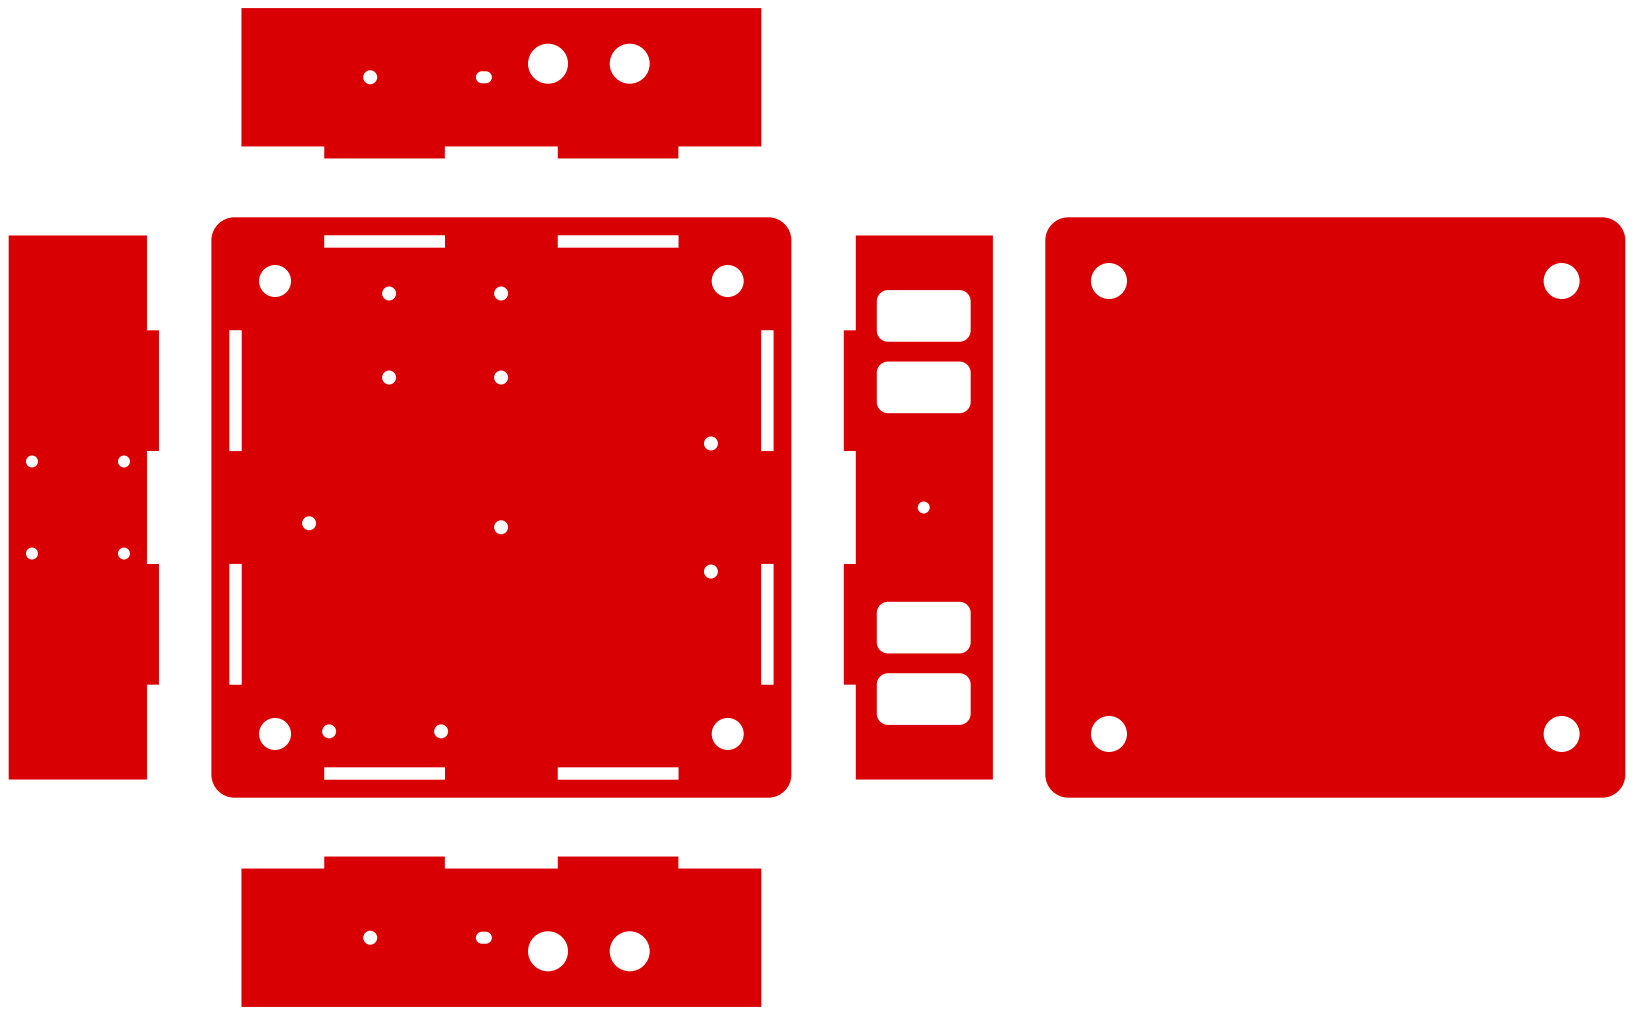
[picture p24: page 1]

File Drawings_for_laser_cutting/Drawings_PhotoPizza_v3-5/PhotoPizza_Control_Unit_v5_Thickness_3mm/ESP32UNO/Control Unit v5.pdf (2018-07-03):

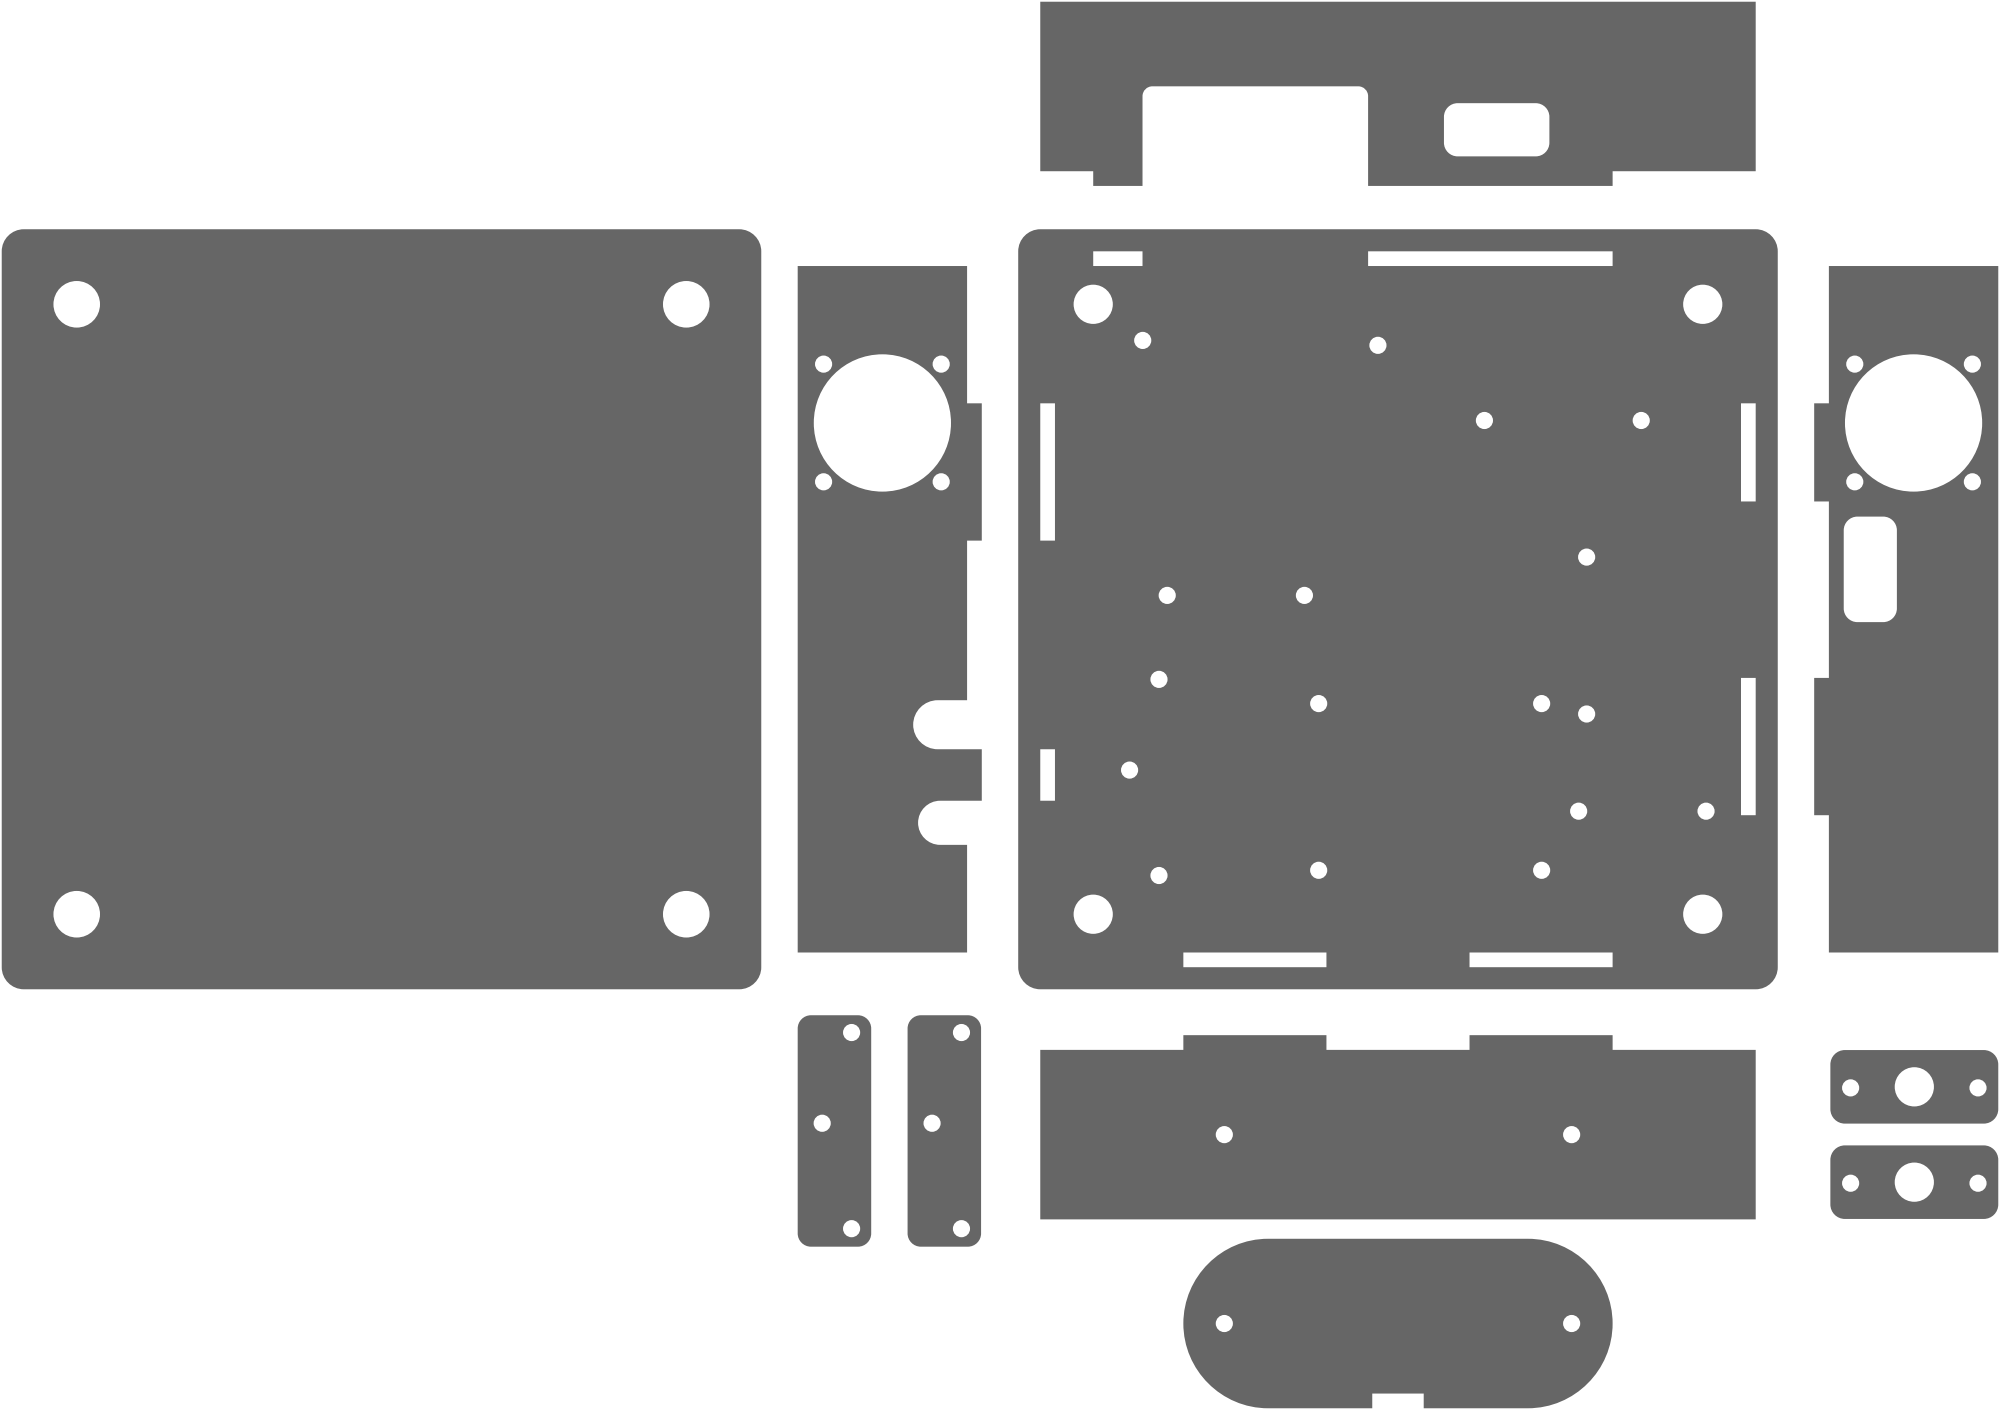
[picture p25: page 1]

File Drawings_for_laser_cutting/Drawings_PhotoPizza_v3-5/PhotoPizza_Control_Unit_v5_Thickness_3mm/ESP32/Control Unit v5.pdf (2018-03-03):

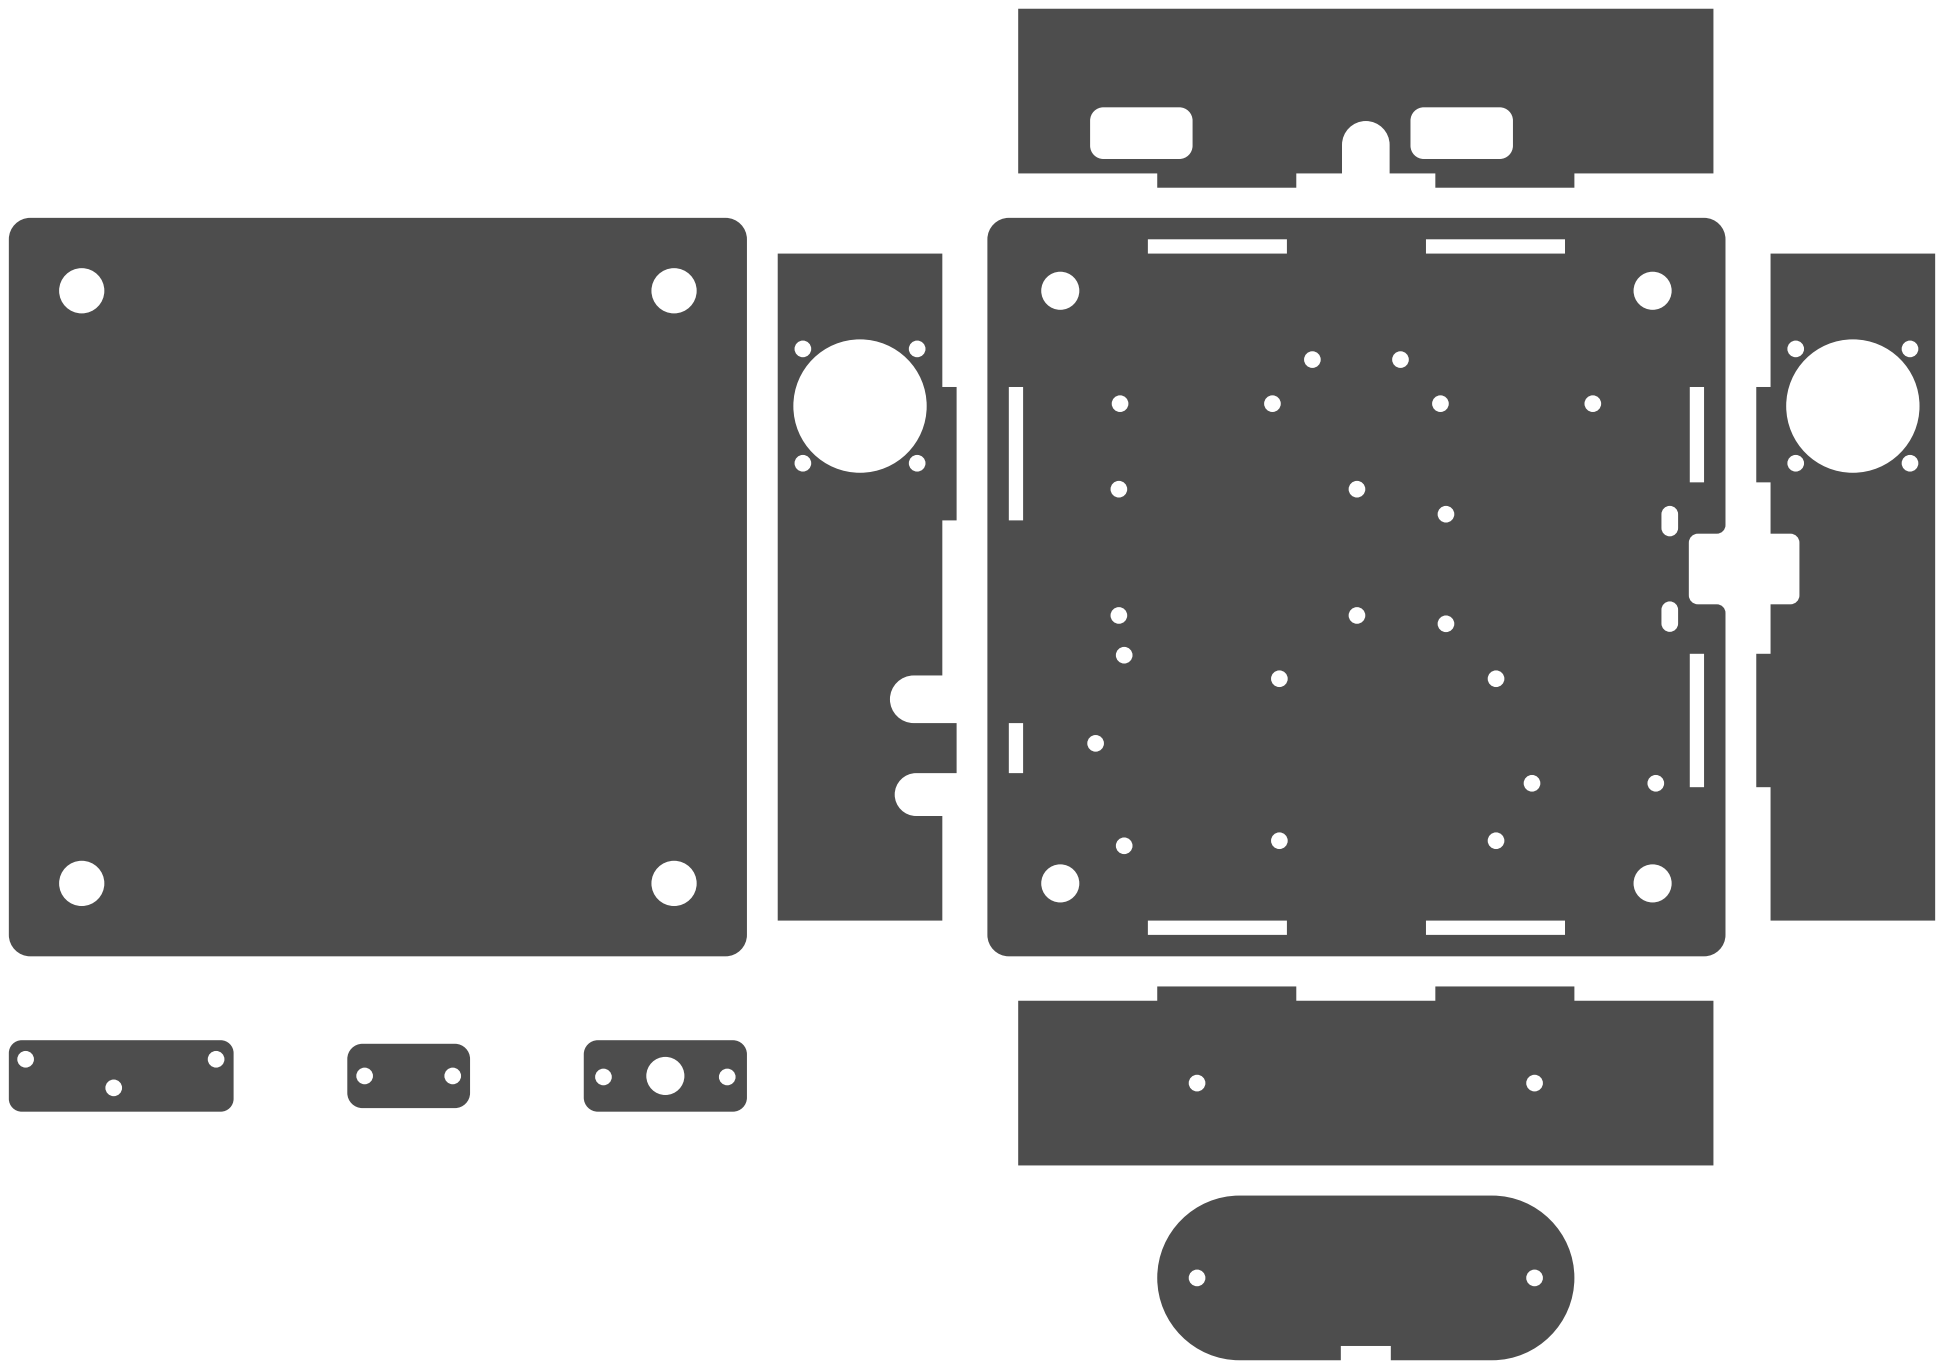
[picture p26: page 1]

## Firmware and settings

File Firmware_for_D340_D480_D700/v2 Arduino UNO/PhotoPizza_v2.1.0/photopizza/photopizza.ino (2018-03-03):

/**
 * File: photopizza.ino
 * Created on: 22 feb 2015 г.
 * Description:
 * PhotoPizza DIY is an open source project of 360° product photography turntable.
 *
 * Author: Roman Savrulin <romeo.deepmind@gmail.com>
 * Project Author: Vladimir Matiyasevith <vladimir.m@makerdrive.com>
 * Project Site: PhotoPizza.org
 *
 * Copyright: 2015 MakerDrive
 * Copying permission statement:
 *  This file is part of PhotoPizza DIY.
 *
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
 */

/////////////
//need to include libs here, because of compile error in other files.
#include <EEPROM.h>
#include <Arduino.h>
#include <LiquidCrystal.h>
#include <Wire.h>

#include <AccelStepper.h>
#include <LiquidCrystal_I2C.h>
#include <SoftTimer.h>
////////////
#include "lcdIrController.h"
#include "presetManager.h"
#include "IRReceiver.h"

using namespace PhotoPizza;
static presetManager *presetMgr = NULL;
static lcdIrController controller;

String inputString = ""; // input string buffer
boolean stringComplete = false; // whether the string is complete

////////////////////////////////////////////////////////////////////////////////////

void setup() {
  Serial.begin(115200);
  controller.init();
  presetMgr = presetManager::get();

  // reserve 200 bytes for the inputString:
  inputString.reserve(200);
}

void yield() {
  if (presetMgr)
    presetMgr->loop(); //very carefully! do not allow delay call in presetMgr
}

void loop() {
  presetMgr->loop();
  controller.loop();
  SoftTimer.loop();

  if (stringComplete) {
    Serial.println(controller.emulateBtn(inputString));
    // clear the string:
    inputString = F("");
    stringComplete = false;
  }
}

/*
 SerialEvent occurs whenever a new data comes in the
 hardware serial RX.  This routine is run between each
 time loop() runs, so using delay inside loop can delay
 response.  Multiple bytes of data may be available.
 */
void serialEvent() {
  while (Serial.available()) {
    // get the new byte:
    char inChar = (char) Serial.read();
    // add it to the inputString:
    inputString += inChar;
    // if the incoming character is a newline, set a flag
    // so the main loop can do something about it:
    if (inChar == '\n') {
      stringComplete = true;
    }
  }
}

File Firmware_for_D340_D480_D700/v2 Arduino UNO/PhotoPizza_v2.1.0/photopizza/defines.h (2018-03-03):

/**
 * File: defines.h
 * Created on: 22 feb 2015 г.
 * Description:
 * PhotoPizza DIY is an open source project of 360° product photography turntable.
 *
 * Author: Roman Savrulin <romeo.deepmind@gmail.com>
 * Project Author: Vladimir Matiyasevith <vladimir.m@makerdrive.com>
 * Project Site: PhotoPizza.org
 *
 * Copyright: 2015 MakerDrive
 * Copying permission statement:
 *  This file is part of PhotoPizza DIY.
 *
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
 */

#ifndef defines_h
#define defines_h

#define VERSION "V. 2.1.0"

//#define DBG(x) Serial.println((String)x);

#define BOARD_TYPE_NANO 0
#define BOARD_TYPE_UNO 1

#define BOARD_TYPE BOARD_TYPE_NANO

#ifndef BOARD_TYPE
//#define BOARD_TYPE BOARD_TYPE_UNO
#endif

#if (BOARD_TYPE == BOARD_TYPE_NANO)
#define MOTOR_STP_PIN 6
#define MOTOR_DIR_PIN 3
#define RELAY_PIN     11
#elif (BOARD_TYPE == BOARD_TYPE_UNO)
#define MOTOR_STP_PIN 12
#define MOTOR_DIR_PIN 13
#define RELAY_PIN     11
#else
#error "Board Not Supported!"
#endif


#define RELAY_HOLD_TIMEOUT 100

////  PARAMS
#define SPEED_MIN 1
#define SPEED_MAX 4300
#define SPEED_STEP 50

#define STEPS_MIN 0
#define STEPS_MAX 200000000  
#define STEPS_STEP 1000

#define ACC_MIN 0
#define ACC_MAX 50000
#define ACC_STEP 100

#define FRAME_COUNT_MIN 1
#define FRAME_COUNT_MAX 200
#define FRAME_COUNT_STEP 1

#define PAUSE_MIN 0
#define PAUSE_MAX 50000
#define PAUSE_STEP 100
#define PAUSE_NONE   0
#define PAUSE_BURST -1


#define NUM_PROGRAMS 4

#define CW -1  //clockwise
#define CCW 1  //counterclockwise

/////////Ir buttons map
#define BTN_POWER      32640         // pos 0 0
#define BTN_VOL_U      23715         // pos 0 1
#define BTN_FUNC       32385         // pos 0 2

#define BTN_RW         23970         // pos 1 0
#define BTN_PLAY       24480         // pos 1 1
#define BTN_FW         24097         // pos 1 2

#define BTN_CH_D       23979         // pos 2 0
#define BTN_VOL_D      29962         // pos 2 1
#define BTN_CH_U       24229         // pos 2 2


#define BTN_0          22185         // pos 3 0
#define BTN_EQ         23205         // pos 3 1
#define BTN_ST         30855         // pos 3 2

#define BTN_1          29835         // pos 4 0
#define BTN_2          29452         // pos 4 1
#define BTN_3          30982         // pos 4 2
#define BTN_4          31110         // pos 5 0
#define BTN_5          29580         // pos 5 1
#define BTN_6          20655         // pos 5 2
#define BTN_7          31620         // pos 6 0
#define BTN_8          29070         // pos 6 1
#define BTN_9          21165         // pos 6 2

///////// LCD buttons map
#define btnRIGHT  100
#define btnUP     101
#define btnDOWN   102
#define btnLEFT   103
#define btnSELECT 104
#define btnNONE   105

#endif

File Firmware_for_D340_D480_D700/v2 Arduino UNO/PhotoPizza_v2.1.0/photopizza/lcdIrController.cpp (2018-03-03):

/**
 * File: lcdIrController.cpp
 * Created on: 10 mar 2015 г.
 * Description:
 * PhotoPizza DIY is an open source project of 360° product photography turntable.
 *
 * Author: Roman Savrulin <romeo.deepmind@gmail.com>
 * Project Author: Vladimir Matiyasevith <vladimir.m@makerdrive.com>
 * Project Site: PhotoPizza.org
 *
 * Copyright: 2015 MakerDrive
 * Copying permission statement:
 *  This file is part of PhotoPizza DIY.
 *
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
 */

#include "lcdIrController.h"

#include "defines.h"
#include <LiquidCrystal.h>
#include <LiquidCrystal_I2C.h>
#include <AccelStepper.h>
#include "IRReceiver.h"
#include "presetManager.h"

#include "keyboard.h"

namespace PhotoPizza {

#if (BOARD_TYPE == BOARD_TYPE_NANO) //TODO: move lcd to class member???
static LiquidCrystal_I2C lcd(0x27, 16, 2); // select the pins used on the LCD panel
#elif (BOARD_TYPE == BOARD_TYPE_UNO)
    static LiquidCrystal lcd(8, 9, 4, 5, 6, 7); // select the pins used on the LCD panel
#endif

///////////  Presets
/* static */presetManager *lcdIrController::_presetMgr;

void lcdIrController::init() {
#if (BOARD_TYPE == BOARD_TYPE_NANO)
  Wire.begin();
  lcd.init(); // initialize the lcd
  lcd.backlight();
#endif
  lcd.home();
  _presetMgr = presetManager::get();
  sayHello();
  showProgram();
  IrInit();
}

void lcdIrController::sayHello() {
  lcd.begin(16, 2);
  lcd.clear();
  lcd.setCursor(0, 0);
  lcd.print(F("PhotoPizza DIY"));
  Serial.println(F("PhotoPizza DIY " VERSION));
  lcd.setCursor(0, 1);
  lcd.print(F(VERSION));
  delay(2000);
}

void lcdIrController::processKey(kbKeys key) {
  if (_presetMgr->isEdit())
    editMode(key);
  else
    menuMode(key);

  if (_presetMgr->isUpdated())
    showProgram();
}

void lcdIrController::loop() {

  kbKeys key = kbGetKey();
  processKey(key);
}

void lcdIrController::printProgNum() {
  lcd.setCursor(0, 0);
  lcd.print(F("Program"));
  lcd.setCursor(8, 0);
  lcd.print((_presetMgr->getPresetNumber() + 1));
}

void lcdIrController::showProgram() {
  lcd.clear();
  printProgNum();
  lcd.setCursor(10, 0);
  lcd.print(_presetMgr->getPreset()->_dir.toString(true));

  IParam *ptr = _presetMgr->getParam();

  if (_presetMgr->isEdit()) {
    lcd.setCursor(0, 1);
    lcd.print(F(">"));
  } else {
    lcd.setCursor(0, 1);
    lcd.print(F(" "));
  }

  lcd.setCursor(1, 1);
  lcd.print(ptr->getName());
  lcd.setCursor(7, 1);
  lcd.print(ptr->toString());
}

///////////////////////////////////////

void lcdIrController::menuMode(kbKeys key) {
  long val;

  switch (key) {
  case kbPwr:
    _presetMgr->stop();
    _presetMgr->run();
    break;
  case kbUp:
    _presetMgr->nextParam();
    break;

  case kbDown:
    _presetMgr->prevParam();
    break;

  case kbRight:
    _presetMgr->nextPreset();
    break;

  case kbLeft:
    _presetMgr->prevPreset();
    break;

  case kbOk:
    _presetMgr->edit();
    break;

  case kbClear:
    _presetMgr->edit();
    _presetMgr->setValue(0);
    break;

  case kbBksp:
    _presetMgr->changeDirection();
    break;

  default:
    int keyV = kbGetNumericKey(key);
    if (keyV >= 0) {
      _presetMgr->edit();
      _presetMgr->setValue(0);
      val = _presetMgr->getValue() * 10 + keyV;
      _presetMgr->setValue(val);
    }
    break;
  }

  if (key != kbNoKey && key != kbPwr)
    showProgram();
}

void lcdIrController::editMode(kbKeys key) {
  long val;

  switch (key) {
  case kbPwr:
    _presetMgr->save();
    _presetMgr->stop();
    _presetMgr->run();
    break;
  case kbLeft:
    _presetMgr->discard();
    break;

  case kbOk:
    _presetMgr->save();
    break;

  case kbDown:
    _presetMgr->valueDown();
    break;

  case kbUp:
    _presetMgr->valueUp();
    break;

  case kbClear:
    _presetMgr->setValue(0);
    break;

  default:
    int keyV = kbGetNumericKey(key);
    if (keyV >= 0) {
      val = _presetMgr->getValue() * 10 + keyV;
      _presetMgr->setValue(val);
    }
    break;
  }
  if (key != kbNoKey && key != kbDown && key != kbUp)
    showProgram();
}

String lcdIrController::emulateBtn(String cmd) {

  String OK = F("OK");
  String ERR = F("ERR");
  String BtnCmd = F("BTN ");

  if (cmd.startsWith(BtnCmd)) {

    cmd.remove(0, BtnCmd.length());

    int key = cmd.toInt();

    if(!(key > kbNoKey && key < kbBtnCount))
      return ERR;

    processKey((kbKeys)key);
    return OK;
  } else
    return ERR;
}

}

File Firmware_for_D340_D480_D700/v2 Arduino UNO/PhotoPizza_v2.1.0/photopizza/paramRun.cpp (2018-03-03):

/**
 * File: paramRun.cpp
 * Created on: 09 mar 2015 г.
 * Description:
 * PhotoPizza DIY is an open source project of 360° product photography turntable.
 *
 * Author: Roman Savrulin <romeo.deepmind@gmail.com>
 * Project Author: Vladimir Matiyasevith <vladimir.m@makerdrive.com>
 * Project Site: PhotoPizza.org
 *
 * Copyright: 2015 MakerDrive
 * Copying permission statement:
 *  This file is part of PhotoPizza DIY.
 *
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
 */

#include "paramRun.h"
#include <AccelStepper.h>
#include <limits.h>

#include "presetManager.h"

namespace PhotoPizza{

AccelStepper stepper(AccelStepper::DRIVER, MOTOR_STP_PIN, MOTOR_DIR_PIN);

boolean paramRun::operator()(){
  if(!_relay.framesLeft() || _val == 0){
    _run = false;
    _val = 0;
    presetManager::get()->discard();
    presetManager::get()->update();
    DBG(F("Finished"));
  }else
    startMotor(NULL);
  return true;
}

void paramRun::stopPreset(){
  if(!_run)
      return;
  _val = 0;
  _delayTime = 0;
  DBG(F("stopping"));
  stepper.stop();
  presetManager::get()->update();
  return;
}

void paramRun::up(){
  paramSpeed *sp = &presetManager::get()->getPreset()->_speed;
  sp->up();
  stepper.setMaxSpeed((long)*sp);
}

void paramRun::down(){
  paramSpeed *sp = &presetManager::get()->getPreset()->_speed;
  sp->down();
  stepper.setMaxSpeed((long)*sp);
}

void paramRun::loop(){
  presetManager *pMgr = presetManager::get();
  if(!stepper.run()){
    if(_run){
      if(!_relay.isRunning() && !_relayCycle && _val){
        _relay.start();
        _relayCycle = true;
      }
      if(!Timer::isRunning()){
        setPeriodMs(pMgr->getPreset()->_pause);
        start();
      }
      if(!_val){
        Timer::stop(true);
        _relay.stop(true);
      }
    }
  }else{
    if(_chunkSize){
      long chunk = stepper.currentPosition()/_chunkSize;
      if(chunk != _lastChunk){
        _relay.start();
        _lastChunk = stepper.currentPosition()/_chunkSize;
      }
    }
  }
}

bool paramRun::startMotor(Task *t){
  preset *preset = presetManager::get()->getPreset();

  DBG(F("Steps") + preset->_steps);
  DBG(F("Speed") + preset->_speed);
  DBG(F("Accel") + preset->_acc);
  DBG(F("Dir") + preset->_dir);
  DBG(F("Frames") + preset->_frames);
  DBG(F("Pause") + preset->_pause);

  _relayCycle = false;
  long steps = preset->_steps * preset->_dir;
  _chunkSize = steps/preset->_frames;
  _lastChunk = 0;

  if(preset->_pause > PAUSE_NONE){
    steps /= preset->_frames;
    DBG(F("Splitting ") + preset->_steps + F(" in ") + preset->_pause + F("chunks."));
    DBG(F("Chunk size: ") + steps);
    _chunkSize = 0; //disable relay triggering for pause: none mode
  }

  stepper.setCurrentPosition(0L);
  if(preset->_acc == 0){
    stepper.setAcceleration(10000000); //no acc.
  }else
    stepper.setAcceleration(preset->_acc);
  if(steps != 0){
    stepper.moveTo(steps);
  }else
    stepper.moveTo(LONG_MAX * preset->_dir);
  stepper.setMaxSpeed(preset->_speed);

  return false;
}

void paramRun::edit() {
  if(_run)
    return;
  DBG(F("Run"));
  _val = 1;
  _run = true;
  _relay._frameCount = presetManager::get()->getPreset()->_frames;
  startMotor(NULL);

  presetManager::get()->update();
}

};

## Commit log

2017-09-25 The display of steps during calibration is disabled
2017-10-03 fixed bug with relay
    [photopizza_espruino.js]
2017-10-03 The principle of calibration has been changed
2017-10-03 Fixed missing buttons
2017-10-04 Fixed a bug of starting infinite rotation in parallel with the shooting mode
    [photopizza_espruino.js]
2017-10-05 Added drawings for laser cutting
2017-11-30 New feature: Laser control. Pin P6.
2017-12-05 relay invert
2018-03-03 New version v5
    [Control Unit v5.dwg]
2018-03-03 Renaming folders
    [Control Unit v5.dwg]
2018-06-14 WiFi remote - bug fix
    [photopizza_esp32_v5.js]
2018-07-03 New drawing for the control unit
    ESP32UNO
    [Control Unit v5.dwg]
2018-08-16 Added a new format for cutting material
    DWG
    [PhotoPizza D340 v3.dwg, PhotoPizza D480 v3.dwg, PhotoPizza D700 v3.dwg]
2019-10-02 New firmware version
    + work in the mode of the Wi-Fi access point.
    + connection to the Wi-Fi access point.
    + engine lock in standby mode. It is turned on by a button on the remote control.
    + When you press a button on the remote control, a test shot is taken.
    Bug fixes.
    [photopizza_esp32_v6_min.js]
2021-06-11 Add files via upload
    1. New size of the turntable, diameter 850 mm.
    2. A new way of pressing the motor against a rotating disk.
    [PhotoPizza_Control_Unit_v7_Thickness_3mm.dwg, PhotoPizza_Control_Unit_v7_Thickness_3mm.dxf, PhotoPizza_D340_v7_Thickness_10mm.dwg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]
2021-06-11 Transferring old drawings to another folder
    [Control Unit v5.dwg, PhotoPizza D340 v3.dwg, PhotoPizza D480 v3.dwg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]
2022-02-19 New turntable
    [D250.dwg, D250.dxf]
2025-03-15 Reorder sections in README.md for better flow
2025-03-15 Add information about ComplexScan prototype in 3D Scanning Examples section

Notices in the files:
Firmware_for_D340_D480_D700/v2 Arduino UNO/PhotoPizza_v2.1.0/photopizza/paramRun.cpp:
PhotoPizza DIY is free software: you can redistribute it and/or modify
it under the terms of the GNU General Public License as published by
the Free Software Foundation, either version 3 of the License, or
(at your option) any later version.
